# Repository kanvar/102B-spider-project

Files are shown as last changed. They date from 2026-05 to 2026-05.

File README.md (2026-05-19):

# Spider Seeder Summary

The Spider Seeder Robot was built for ME 102B, Spring 2026 — it's a six-legged robot that plants seeds in rough terrain. The idea is for ecological restoration work, where you need to get a lot of seeds into uneven ground and doing it by hand is slow while big machinery isn't precise enough and cannot navigate the rough terrain. There are five subsystems: the six-legged chassis, a 12V DC motor drill, a stepper-driven seed dispenser, the sensors, and an ESP32 handling control and communications.

The robot can walk, but we decided to have it plant from a fixed standing position instead of dealing with full gait planning. It runs an event-driven state machine: lower the body using the servos to push the drill into the soil, retract, drop the seeds, move over, then sweep a leg over to cover the hole. Skipping the walking let us put our effort into making the planting sequence flawless, which made sense for our assignment.

On the electrical side, the ESP32 runs the state machine (IDLE → DRILLING → SEEDING → COVERING, with a global ABORT), handles WiFi, and drives all the I/O. Two PCA9685 boards run the 18 servos over I²C, a VNH5019 driver handles the 12 V drill motor, and a ULN2003 board runs the seed stepper. The part I'm most proud of ont his bot is the custom power distribution board I soldered in order to take power from the battery and distribute it to all components. There's also an IR flame sensor that triggers an immediate abort if it goes off. Due to our extreme electronics setup for a Mechanical Engineering course (extremly overkill) we were honored with reciving the award for the best Electromechanical Design award.

This GitHub has the final mechanical, electrical, and software development for the project as well as our final report. The biggest thing for future improvements: define the state machine, and define electronics before trying to mechanically integrate. We learned this the hard way — we selected most of our electronics after the main design and caused lots of sizing and late prototypying which was the reason we couldn't fully demo our walking sequence.

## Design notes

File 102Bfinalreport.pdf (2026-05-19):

ME 102B · Mechatronics Design · Spring 2026 | Spider Seeder Robot

Spider Seeder
ME 102B — Mechatronics Design · Spring 2026 | Team #21
Kanvar Soin | Raul Hernandez | Mark Polezhaev | Jesse Ramirez | Carlos Avina
| | May 14, 2026

### 1. Opportunity

Ecological restoration requires planting large numbers of seeds in uneven, remote terrain where manual methods are labor intensive and conventional machinery lacks precision. The Spider Seeder Robot fills this gap with a compact, autonomous platform that navigates rough ground, drills to consistent depth, and dispenses seeds in a single integrated cycle using low-cost components suited for replication and future development.

### 2. System Overview and High-Level Strategy

The robot integrates five subsystems: a six-legged servo-driven chassis, a DC motor drill, a stepper-motor seed dispenser, a sensor suite, and an ESP32 control and communication layer (Figure 1).
The robot has the ability to achieve locomotion; however, the robot plants from a fixed standing position using an event-driven state machine: it lowers its body via coxa servo deflection to drive the drill into soil, retracts, dispenses seeds, and sweeps a leg to cover the hole. This focused the control effort on depth sensing and actuation reliability over gait planning, appropriate for a first-generation prototype.

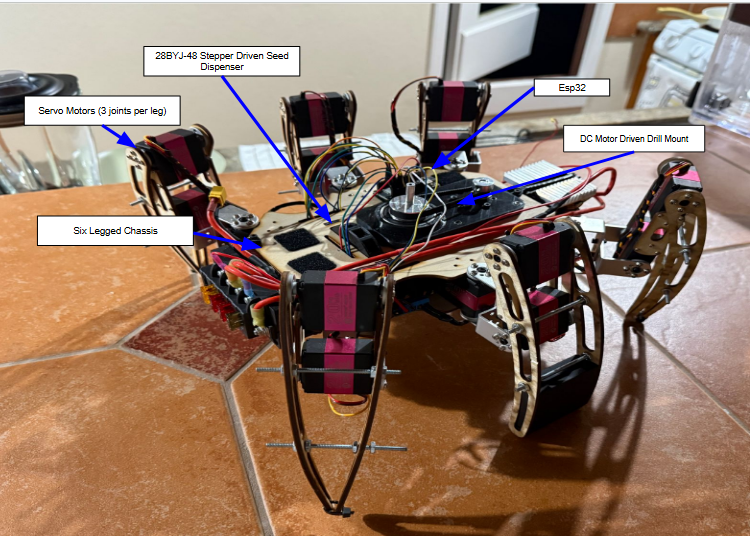
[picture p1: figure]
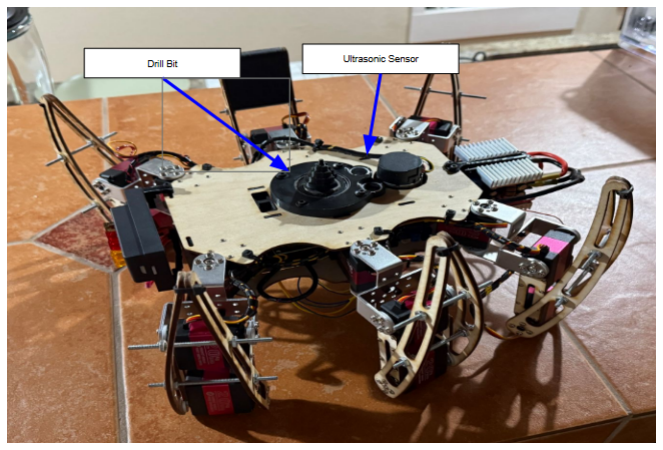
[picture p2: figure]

(a) Annotated top view. | (b) Annotated bottom view.
Figure 1: Annotated photos of the fully assembled Spider Seeder Robot. The labeled views identify the main mechanical, sensing, and actuation subsystems, including the six-legged chassis, servo motors, drill subsystem, ultrasonic sensor, ESP32 controller, and stepper-driven seed dispenser. These photos serve as a visual reference for the integrated prototype and the key components used during the planting sequence.

### 3. Desired vs. Achieved Specifications

Table 1 compares design targets against achieved performance. Values marked XX will be filled with measured results from final testing.

Table 1: Design targets vs. achieved specifications.

Parameter | Target | Achieved
Drilling depth | 5 cm | 7 cm
Drill motor actuation | Full PWM (12 V, 255/255) | Full PWM (12 V, 255/255)
Body descent range (coxa) 90→45 | 90→45
Depth sensing method | Tare + relative threshold | Implemented, ±0.5 cm
Covering sweep reps | 2 reps | 2 reps

### 4. Electrical and Control Architecture

The ESP32 manages the state machine, WiFi communication, and all I/O. Two PCA9685 PWM boards drive the 18 MG996R servos over I²C, while freeing ESP32 PWM channels. The 12 V drill motor is controlled through a VNH5019 driver, and the 28BYJ-48 seed stepper is driven by a ULN2003 board. All pin assignments are stored in Config.h.
Sensors: The HC-SR04 supports closed-loop depth control using tareDistance(), which averages five IDLE baseline readings and compares later drilling readings within ±0.5 cm. The normally-high IR flame sensor is checked every loop and immediately triggers ABORT if activated.
Communication: The ESP32 hosts the SpiderRobot 102B WiFi access point. The browser GUI sends commands through GET /command?cmd=... and polls GET /status every 1.5 s for JSON telemetry.
Figure 2 shows the full circuit diagram.

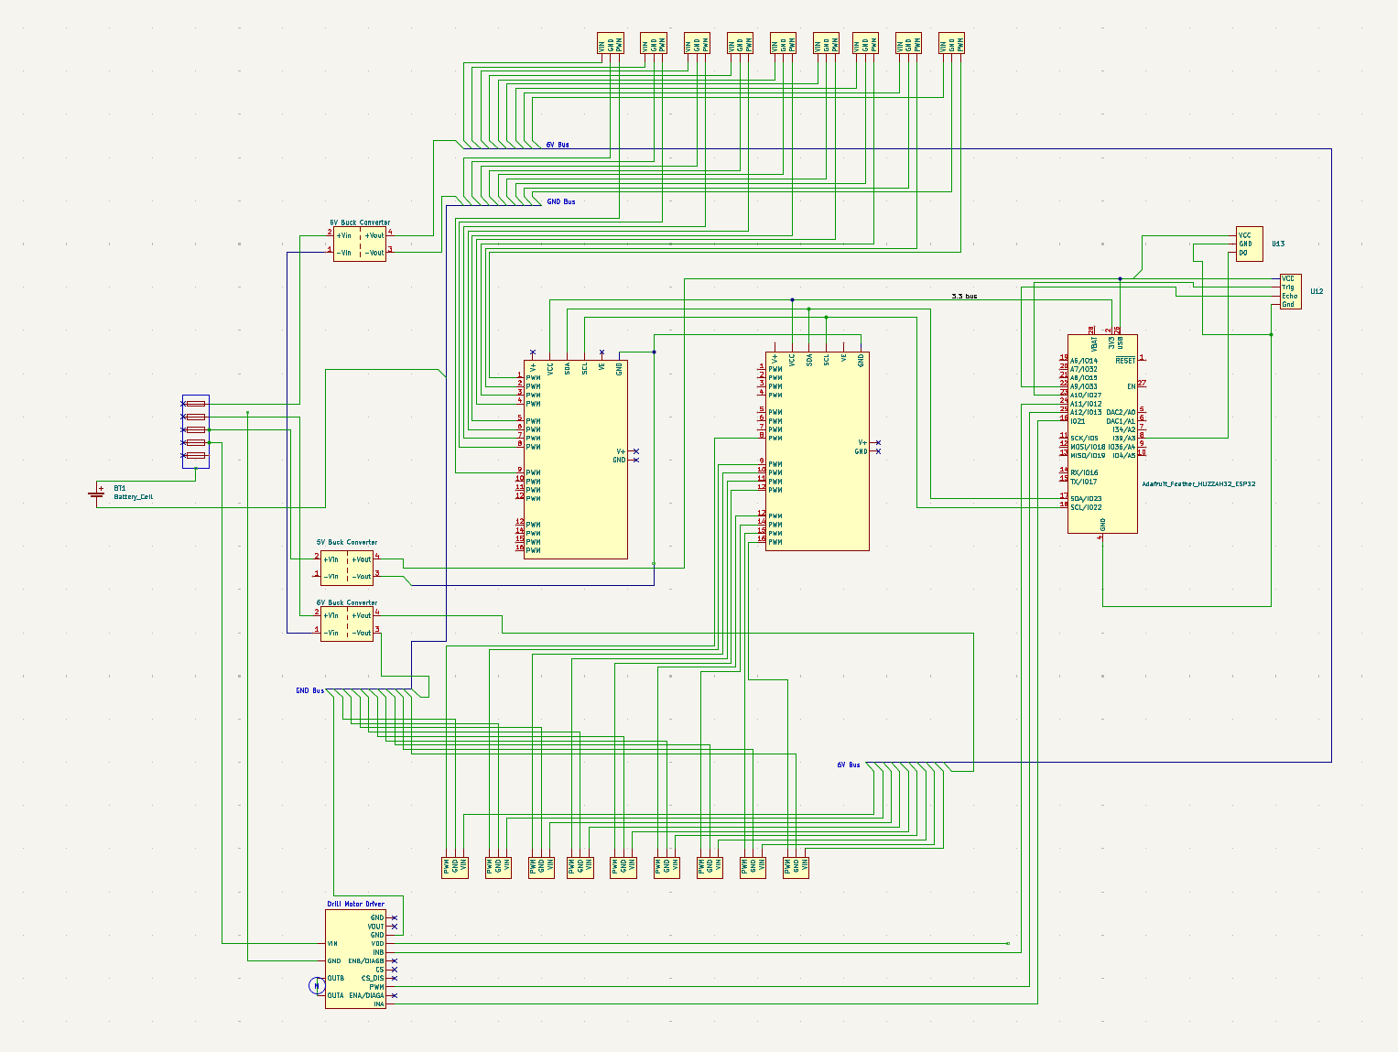
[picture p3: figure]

Figure 2: Circuit diagram showing ESP32 GPIO assignments, PCA9685 I²C servo driver connections, L298N drill motor driver, ULN2003 stepper driver, HC-SR04 ultrasonic wiring, IR flame sensor input, and power distribution.

### 5. State Machine and Event-Driven Logic

The robot’s behavior is governed by a finite state machine implemented in StateMachine.cpp. Each state has a dedicated service function with a static bool firstEntry guard that executes one-time initialization on state entry and ongoing per-loop logic on subsequent calls. stateMachineLoop() is called every Arduino loop() iteration, ensuring non-blocking operation except during the SEEDING and COVERING phases, which use blocking delay() calls for actuator timing precision.
Table 2 describes each state, its entry action, and its exit condition. Figure 3 shows the transition diagram.

Table 2: State machine summary.

State | Entry action | Exit condition
IDLE | Zero all 18 servos; tare ul- trasonic baseline (5-sample
| avg) | Operator | sends
| | STATE:DRILLING | via
| | GUI
DRILLING | Drill ON; lower body (coxa
| 90 → 45), then lift; speed
| scales with distance

Returns to baseline ±0.5 cm
| | or coxa reaches 90
SEEDING | Drill OFF; stepper rotates
| 2500 steps

Stepper completes (auto-
| | advance)
COVERING Right-middle leg sweeps
| C/F; 2× reps

Animation completes (auto-
| | advance to IDLE)
ABORT | All actuators disabled | Operator | sends

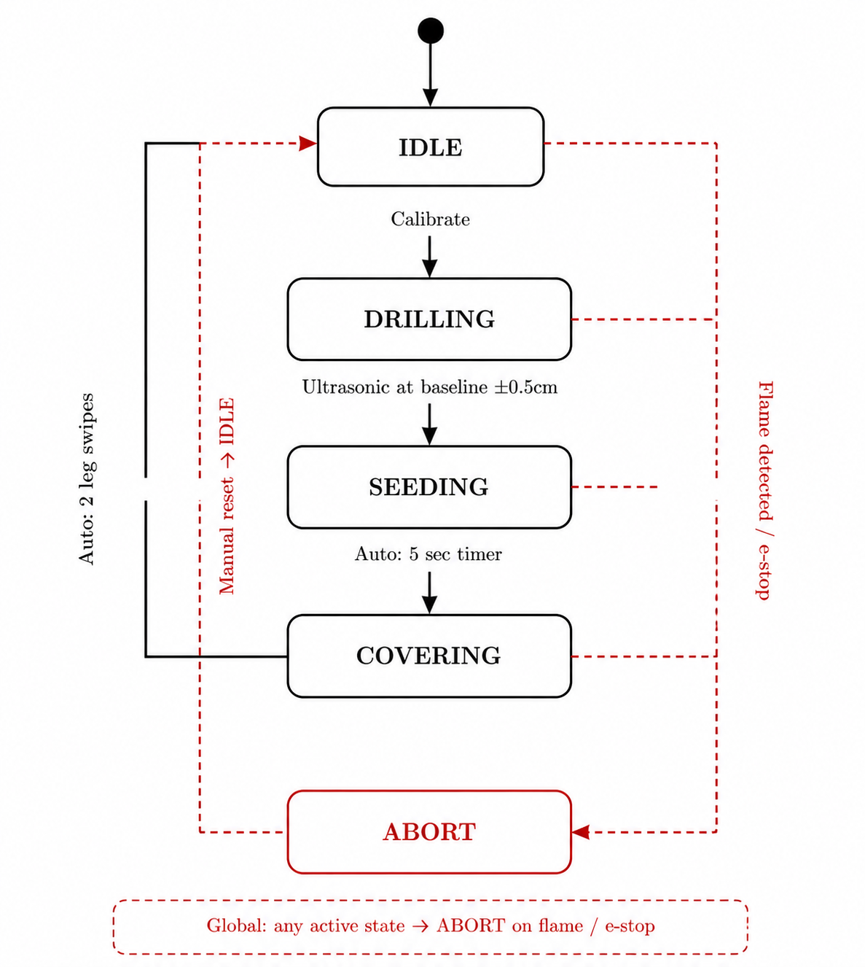
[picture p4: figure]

STATE:IDLE | Figure 3: State transition diagram.

### 6. Function-Critical Decisions and Calculations

### 6.1. Coxa Servo Selection — Body-Lowering Torque

Each of the six coxa servos must support 1
6

of the robot’s weight through a moment arm equal to femur length L = 7 in = 0.178 m:

τreq =

m g
6
- L =

3.205 × 9.81
6
× 0.178 ≈ 0.932 N m | (1)

The installed servo is rated at 20 kg cm = 1.962 N m, yielding a design safety factor of SF = 1.962 / 0.932 ≈ 2.1, providing margin for dynamic loads during soil penetration.

### 6.2. Drill Motor Driver Selection

The Pololu 25D gearmotor operates at 12 V with a rated operating current of Iop = 0.82 A (at peak efficiency):

Pin = V · Iop = 12 × 0.82 = 9.84W | (2)

delivering a maximum mechanical output of 8.9W at 44 % efficiency. Stall current is Istall = 5.0 A. The VNH5019 motor driver is rated at 12 A continuous (30 A peak), providing a driver safety factor of 12 / 5.0 = 2.4 even at stall, well within the thermal envelope for the 60 s maximum drill cycle.

### 6.3. Ultrasonic Depth Sensing — Tare-and-Compare Algorithm

Rather than a fixed threshold, tareDistance() samples five readings at IDLE entry to establish a terrain-relative baseline. The DRILLING-to-SEEDING transition fires when:

|dmeasured − dbaseline| ≤ 0.5 cm | (3)

This makes depth control invariant to terrain height, mounting variation, and battery sag, at the cost of a brief initialization delay per cycle.

### 7. Reflection for Future Students

The most useful decision was defining the state machine, WiFi command protocol, and /status JSON format before full firmware integration. This gave the team a shared interface and made debugging easier.
Future teams should lock all pin assignments in Config.h during initial wiring and build telemetry into the system from the beginning. Adding the telemetry endpoint late required changes across multiple files and introduced a connection-loss bug.

A. Bill of Materials
Component | Description / Supplier | Qty | Unit $ | Total $

Actuation
Servo Motor | 20 kg·cm, AliExpress | 18 | 10.74 | 252.13
Gearmotor (Drill) | 12 V brushed DC, Pololu | 1 | 56.00 | 69.90
Stepper Motor | NEMA seed dispenser, Stepper Online | 1 | 20.49 | 20.49

Electronics / Control
PWM Expander | PCA9685 16-ch I²C, Amazon | 2 | 9.99 | 21.28
Motor Driver | Pololu VNH5019, drill motor | 1 | 12.95 | 14.21
Logic Converter | Bi-directional 3.3 V/5 V, Amazon | 1 | 4.99 | 6.29
IR Flame Sensor | Digital, 760–1100 nm, Amazon | 1 | 7.99 | 9.29
HC-SR04 Ultrasonic | 2–400 cm, on hand | 1 | – | 0.00
Capacitors | Servo rail bulk caps, Amazon | 1 | 6.99 | 8.29
Protoboard | Amazon | 2 | 8.99 | 19.28

Power
3S LiPo Battery | 5200 mAh, XT60, Amazon | 2 | – | 90.34
5A Buck Converter | 5 V output, Amazon | 1 | 14.99 | 16.29
12V Buck Converter | 12 V output, Amazon | 1 | 12.99 | 14.29
Power Dist. Board | Amazon | 1 | 6.99 | 8.29
Terminal Block | Amazon | 1 | 14.99 | 14.99
Grounding Bus | 6-position brass terminal, Amazon | 1 | 8.39 | 9.69
XT60 Connector | Amazon | 1 | 9.89 | 11.19
30 A Fuse | Amazon | 1 | 4.86 | 6.16

Mechanical Structure
Aluminum 6061 | Assorted cuts, Jacobs/Amazon | – | – | 114.24
Timing Pulley 2GT | 2-piece set, Amazon | 1 | 8.99 | 9.91
Bearing | Amazon | 1 | 16.99 | 22.03
Drill Brackets | Pololu | 1 | 10.95 | 12.22
Step Drill Bit | Home Depot | 1 | 8.97 | 10.17
Coupler (Drill) | Walmart | 1 | 9.99 | 10.76
Aluminum Shaft | Amazon | 1 | 9.99 | 11.29
Hardware | M3/M4 screws, McMaster/on hand | – | – | 3.11
Sleeve Tube | Amazon | 1 | 7.99 | 9.29

Wiring / Connectors
Wire, assorted | 14–24 AWG, Amazon | – | – | 123.46
Wire Tubing | Amazon | 1 | 10.00 | 11.30
Heat Shrink Kit | Amazon | 1 | 9.99 | 11.29
Banana Connectors | Male/female set, Amazon | 1 | 9.99 | 11.29
Pin Headers | Amazon | 1 | 11.99 | 13.29

Miscellaneous
Seeds | Amazon | 1 | 5.41 | 5.41
Adhesive Pads | Amazon | 1 | 8.99 | 8.99
Connector Kit | 80 pc assorted, Amazon | 1 | 4.99 | 4.99
Breadboard | On hand | 1 | – | 0.00
| | | Total | $993.73
B. CAD Images

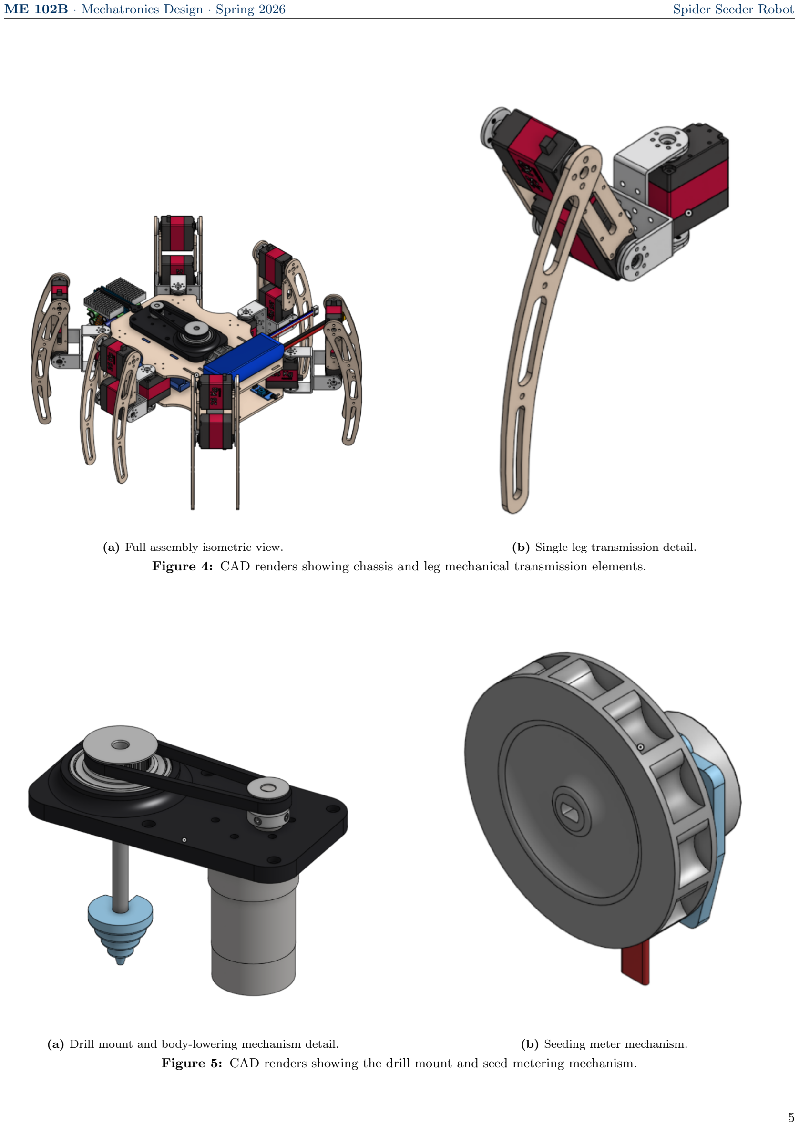
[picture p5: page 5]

(a) Full assembly isometric view. | (b) Single leg transmission detail.
Figure 4: CAD renders showing chassis and leg mechanical transmission elements.
(a) Drill mount and body-lowering mechanism detail. | (b) Seeding meter mechanism.
Figure 5: CAD renders showing the drill mount and seed metering mechanism.

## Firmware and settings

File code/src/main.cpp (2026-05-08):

#include <Arduino.h>
#include "control/StateMachine.h"
#include "control/WiFiCommand.h"
#include "actuators/DrillMotor.h"
#include "actuators/SeederMotor.h"
#include "motion/LegController.h"
#include "sensors/DistanceSensor.h"

DrillMotor drill;
SeederMotor seeder;

void setup() {
  Serial.begin(115200);
  delay(200);

  drill.begin();
  seeder.begin();
  legSetup();
  distanceSensorSetup();
  wifiCommandSetup();
  stateMachineSetup();
}

void loop() {
  wifiCommandLoop();
  stateMachineLoop();
}

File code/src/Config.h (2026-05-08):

#pragma once
#ifndef CONFIG_H
#define CONFIG_H
#include <stdint.h>


struct ServoAddr { uint8_t bus; uint8_t ch; };


constexpr ServoAddr leftFront_H = { 0x40, 2 };
constexpr ServoAddr leftFront_C = { 0x40, 3 };
constexpr ServoAddr leftFront_F = { 0x40, 0 };

constexpr ServoAddr leftMiddle_H = { 0x60, 7 };
constexpr ServoAddr leftMiddle_C = { 0x60, 5 };
constexpr ServoAddr leftMiddle_F = { 0x60, 6 };

constexpr ServoAddr leftBack_H = { 0x40, 7 };
constexpr ServoAddr leftBack_C = { 0x40, 5 };
constexpr ServoAddr leftBack_F = { 0x40, 6 };


constexpr ServoAddr rightFront_H = { 0x60, 13 };
constexpr ServoAddr rightFront_C = { 0x60, 14 };
constexpr ServoAddr rightFront_F = { 0x60, 15 };

constexpr ServoAddr rightMiddle_H = { 0x60, 10 };
constexpr ServoAddr rightMiddle_C = { 0x60, 11 };
constexpr ServoAddr rightMiddle_F = { 0x60, 9 };

constexpr ServoAddr rightBack_H = { 0x40, 12 };
constexpr ServoAddr rightBack_C = { 0x40, 14 };
constexpr ServoAddr rightBack_F = { 0x40, 13 };

constexpr int TRIG_PIN = 4;
constexpr int ECHO_PIN = 5;

constexpr int FIRE_SENSOR_PIN = 15;

constexpr int DRILL_INA_PIN = 13;
constexpr int DRILL_INB_PIN = 33;
constexpr int DRILL_PWM_PIN = 27;


constexpr int SEEDER_IN1_PIN = 19;
constexpr int SEEDER_IN2_PIN = 21;
constexpr int SEEDER_IN3_PIN = 14;
constexpr int SEEDER_IN4_PIN = 32;


constexpr float PLANT_THRESHOLD_CM = 10.0;
constexpr float WALK_THRESHOLD_CM  = 10.0;


constexpr int DRILL_DEFAULT_SPEED = 255;


constexpr int SEEDER_STEPS_PER_REV = 400;
constexpr int SEEDER_STEP_DELAY_MS = 2;


constexpr unsigned long SENSOR_INTERVAL_MS = 100;
constexpr unsigned long GAIT_STEP_MS       = 600;
constexpr unsigned long IDLE_PRINT_MS      = 1000;

constexpr const char* WIFI_AP_SSID = "SpiderRobot_102B";
constexpr const char* WIFI_AP_PASSWORD = "123456789";

#endif

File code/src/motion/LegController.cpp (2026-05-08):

#include <Arduino.h>
#include <Wire.h>
#include <Adafruit_PWMServoDriver.h>
#include "LegController.h"
#include "../Config.h"

static Adafruit_PWMServoDriver pwmBack = Adafruit_PWMServoDriver(0x40);
static Adafruit_PWMServoDriver pwmFront = Adafruit_PWMServoDriver(0x60);

// PWM frequency for hobby servos
#define SERVO_FREQ_HZ 50

#define PULSE_MIN_TICKS 102
#define PULSE_MAX_TICKS 512


void legSetup()
{
  Serial.println("LegController: setup");

  Wire.begin(22, 20); // SDA, SCL

  pwmBack.begin();
  pwmBack.setPWMFreq(SERVO_FREQ_HZ);

  pwmFront.begin();
  pwmFront.setPWMFreq(SERVO_FREQ_HZ);

  delay(100);

  Serial.println("LegController: both boards initialized");
}


void writeServoAngle(uint8_t bus, uint8_t channel, int angle)
{
  if (angle < 0)
    angle = 0;
  if (angle > 180)
    angle = 180;

  int ticks = map(angle, 0, 180, PULSE_MIN_TICKS, PULSE_MAX_TICKS);

  // Send to the correct board
  if (bus == 0x40)
  {
    pwmBack.setPWM(channel, 0, ticks);
  }
  else if (bus == 0x60)
  {
    pwmFront.setPWM(channel, 0, ticks);
  }
  else
  {
    Serial.print("LegController: unknown bus 0x");
    Serial.println(bus, HEX);
  }
}

void zeroAllServos()
{
  Serial.println("LegController: setting all servos to starting pose");

  writeServoAngle(leftFront_H.bus, leftFront_H.ch, 90);
  writeServoAngle(leftMiddle_H.bus, leftMiddle_H.ch, 90);
  writeServoAngle(leftBack_H.bus, leftBack_H.ch, 90);
  writeServoAngle(rightFront_H.bus, rightFront_H.ch, 90);
  writeServoAngle(rightMiddle_H.bus, rightMiddle_H.ch, 90);
  writeServoAngle(rightBack_H.bus, rightBack_H.ch, 90);
  delay(100);


  writeServoAngle(leftFront_C.bus, leftFront_C.ch, 90);
  writeServoAngle(leftMiddle_C.bus, leftMiddle_C.ch, 90);
  writeServoAngle(leftBack_C.bus, leftBack_C.ch, 90);
  writeServoAngle(rightFront_C.bus, rightFront_C.ch, 90);
  writeServoAngle(rightMiddle_C.bus, rightMiddle_C.ch, 90);
  writeServoAngle(rightBack_C.bus, rightBack_C.ch, 90);
  delay(100);


  writeServoAngle(leftFront_F.bus, leftFront_F.ch, 10);
  writeServoAngle(leftMiddle_F.bus, leftMiddle_F.ch, 10);
  writeServoAngle(leftBack_F.bus, leftBack_F.ch, 10);
  writeServoAngle(rightFront_F.bus, rightFront_F.ch, 10);
  writeServoAngle(rightMiddle_F.bus, rightMiddle_F.ch, 10);
  writeServoAngle(rightBack_F.bus, rightBack_F.ch, 10);
  delay(100);

  Serial.println("LegController: starting pose set");
}

void walkingIDLE()
{
  Serial.println("LegController: setting all servos to walking pose");

  writeServoAngle(leftFront_H.bus, leftFront_H.ch, 90);
  writeServoAngle(leftMiddle_H.bus, leftMiddle_H.ch, 90);
  writeServoAngle(leftBack_H.bus, leftBack_H.ch, 90);
  writeServoAngle(rightFront_H.bus, rightFront_H.ch, 90);
  writeServoAngle(rightMiddle_H.bus, rightMiddle_H.ch, 90);
  writeServoAngle(rightBack_H.bus, rightBack_H.ch, 90);
  delay(100);

  writeServoAngle(leftFront_C.bus, leftFront_C.ch, 110);
  writeServoAngle(leftMiddle_C.bus, leftMiddle_C.ch, 110);
  writeServoAngle(leftBack_C.bus, leftBack_C.ch, 110);
  writeServoAngle(rightFront_C.bus, rightFront_C.ch, 110);
  writeServoAngle(rightMiddle_C.bus, rightMiddle_C.ch, 110);
  writeServoAngle(rightBack_C.bus, rightBack_C.ch, 110);
  delay(100);

  writeServoAngle(leftFront_F.bus, leftFront_F.ch, 40);
  writeServoAngle(leftMiddle_F.bus, leftMiddle_F.ch, 40);
  writeServoAngle(leftBack_F.bus, leftBack_F.ch, 40);
  writeServoAngle(rightFront_F.bus, rightFront_F.ch, 40);
  writeServoAngle(rightMiddle_F.bus, rightMiddle_F.ch, 40);
  writeServoAngle(rightBack_F.bus, rightBack_F.ch, 40);
  delay(100);

  Serial.println("LegController: starting pose set");
}

void seedingMoveForward()
{
  const int leftStart = 90;
  const int rightStart = 90;
  const int leftTarget = 120;
  const int rightTarget = 60;
  const int stepDelayMs = 10;

  int leftStep = (leftStart < leftTarget) ? 1 : -1;
  int rightStep = (rightStart < rightTarget) ? 1 : -1;

  int leftAngle = leftStart;
  int rightAngle = rightStart;

  while (leftAngle != leftTarget || rightAngle != rightTarget)
  {
    if (leftAngle != leftTarget)
      leftAngle += leftStep;
    if (rightAngle != rightTarget)
      rightAngle += rightStep;

    writeServoAngle(leftFront_H.bus, leftFront_H.ch, leftAngle);
    writeServoAngle(leftMiddle_H.bus, leftMiddle_H.ch, leftAngle);
    writeServoAngle(leftBack_H.bus, leftBack_H.ch, leftAngle);
    writeServoAngle(rightFront_H.bus, rightFront_H.ch, rightAngle);
    writeServoAngle(rightMiddle_H.bus, rightMiddle_H.ch, rightAngle);
    writeServoAngle(rightBack_H.bus, rightBack_H.ch, rightAngle);

    delay(stepDelayMs);
  }
}

void sideStepRight()
{
  writeServoAngle(leftFront_C.bus, leftFront_C.ch, 75);
  writeServoAngle(leftBack_C.bus, leftBack_C.ch, 75);
  writeServoAngle(leftFront_F.bus, leftFront_F.ch, 30);
  writeServoAngle(leftBack_F.bus, leftBack_F.ch, 30);
  writeServoAngle(leftFront_H.bus, leftFront_H.ch, 60);
  writeServoAngle(leftBack_H.bus, leftBack_H.ch, 120);
  delay(1000);
  writeServoAngle(leftFront_F.bus, leftFront_F.ch, 70);
  writeServoAngle(leftBack_F.bus, leftBack_F.ch, 70);
  writeServoAngle(leftFront_C.bus, leftFront_C.ch, 150);
  writeServoAngle(leftBack_C.bus, leftBack_C.ch, 150);
  delay(1000);
  writeServoAngle(rightMiddle_C.bus, rightMiddle_C.ch, 100);
  writeServoAngle(leftMiddle_C.bus, leftMiddle_C.ch, 70);
  writeServoAngle(leftMiddle_F.bus, leftMiddle_F.ch, 30);
  writeServoAngle(rightFront_C.bus, rightFront_C.ch, 70);
  writeServoAngle(rightBack_C.bus, rightBack_C.ch, 70);
  writeServoAngle(rightFront_F.bus, rightFront_F.ch, 30);
  writeServoAngle(rightBack_F.bus, rightBack_F.ch, 30);
  delay(1000);

  const int stepDelayMs = 20;

  int lfF = 70;
  int lfC = 150;
  int rmC = 90;
  int rmF = 10;

  const int lfF_end = 10;
  const int lfC_end = 90;
  const int rmC_end = 150;
  const int rmF_end = 70;

  while (lfF != lfF_end || lfC != lfC_end || rmC != rmC_end || rmF != rmF_end)
  {
    if (lfF != lfF_end)
      lfF--; // 70  -> 10
    if (lfC != lfC_end)
      lfC--; // 150 -> 90
    if (rmC != rmC_end)
      rmC++; // 90  -> 150
    if (rmF != rmF_end)
      rmF++; // 10  -> 70

    writeServoAngle(leftFront_F.bus, leftFront_F.ch, lfF);
    writeServoAngle(leftBack_F.bus, leftBack_F.ch, lfF);
    writeServoAngle(leftFront_C.bus, leftFront_C.ch, lfC);
    writeServoAngle(leftBack_C.bus, leftBack_C.ch, lfC);
    writeServoAngle(rightMiddle_C.bus, rightMiddle_C.ch, rmC);
    writeServoAngle(rightMiddle_F.bus, rightMiddle_F.ch, rmF);

    delay(stepDelayMs);
  }

  delay(1000);

  writeServoAngle(leftMiddle_C.bus, leftMiddle_C.ch, 100);
  writeServoAngle(leftMiddle_F.bus, leftMiddle_F.ch, 10);
  writeServoAngle(rightFront_C.bus, rightFront_C.ch, 100);
  writeServoAngle(rightBack_C.bus, rightBack_C.ch, 100);
  delay(1000);
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

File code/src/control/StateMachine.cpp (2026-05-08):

#include <Arduino.h>
#include "StateMachine.h"
#include "SerialCommand.h"
#include "WiFiCommand.h"
#include "../motion/LegController.h"
#include "../sensors/DistanceSensor.h"
#include "../actuators/DrillMotor.h"
#include "../actuators/SeederMotor.h"
#include "../Config.h"

extern SeederMotor seeder;
extern DrillMotor drill;

State currentState = IDLE;

//drill configuration

#define DRILL_TRIGGER_CM 3.0
#define COXA_START_ANGLE 90
#define COXA_MIN_ANGLE 45

#define DESCENT_FAR_DISTANCE 20.0
#define DESCENT_NEAR_DISTANCE 5.0
#define DESCENT_FAST_MS 30
#define DESCENT_SLOW_MS 200

#define DRILLING_PHASE_DESCEND 0
#define DRILLING_PHASE_LIFT 1

#define BASELINE_TOLERANCE_CM 0.5

//helper function: state to string

const char *stateToString(State s)
{
  switch (s)
  {
  case IDLE:
    return "IDLE";
  case DRILLING:
    return "DRILLING";
  case SEEDING:
    return "SEEDING";
  case COVERING:
    return "COVERING";
  case ABORT:
    return "ABORT";
  default:
    return "UNKNOWN";
  }
}

//helper function: delay for drilling

unsigned long computeStepDelay(float distance)
{
  if (distance < 0)
  {
    return DESCENT_SLOW_MS;
  }
  else if (distance >= DESCENT_FAR_DISTANCE)
  {
    return DESCENT_FAST_MS;
  }
  else if (distance <= DESCENT_NEAR_DISTANCE)
  {
    return DESCENT_SLOW_MS;
  }
  else
  {
    float t = (distance - DESCENT_NEAR_DISTANCE) /
              (DESCENT_FAR_DISTANCE - DESCENT_NEAR_DISTANCE);
    return DESCENT_SLOW_MS +
           (unsigned long)((DESCENT_FAST_MS - DESCENT_SLOW_MS) * t);
  }
}

//helper function: slow the servos down

void smoothMoveServoAngle(uint8_t bus, uint8_t ch, int startAngle, int endAngle, int stepDelayMs)
{
  if (startAngle < endAngle)
  {
    for (int angle = startAngle; angle <= endAngle; angle++)
    {
      writeServoAngle(bus, ch, angle);
      delay(stepDelayMs);
    }
  }
  else
  {
    for (int angle = startAngle; angle >= endAngle; angle--)
    {
      writeServoAngle(bus, ch, angle);
      delay(stepDelayMs);
    }
  }
}


void stateMachineSetup()
{
  Serial.println("StateMachine: setup");

  currentState = IDLE;

  Serial.print("StateMachine: starting in ");
  Serial.println(stateToString(currentState));
}

//IDLE state

void serviceIdle()
{
  static bool firstEntry = true;

  if (firstEntry)
  {
    Serial.println("IDLE: first entry — zeroing servos and taring ultrasonic");
    // walkingIDLE();
    zeroAllServos();
    delay(2000);
    tareDistance();

    firstEntry = false;

    Serial.println("IDLE: setup complete, monitoring for trigger");
  }

  readDistanceIfReady();

  if (currentState != IDLE)
  {
    firstEntry = true;
  }
}

//drilling state

void serviceDrilling()
{
  static bool firstEntry = true;
  static int currentCoxaAngle = COXA_START_ANGLE;
  static unsigned long lastStepTime = 0;
  static int phase = DRILLING_PHASE_DESCEND;

  if (firstEntry)
  {
    zeroAllServos();
    Serial.println("DRILLING: first entry — drill on, beginning descent");

    drill.on();

    currentCoxaAngle = COXA_START_ANGLE;
    setAllCoxas(currentCoxaAngle);

    phase = DRILLING_PHASE_DESCEND;
    lastStepTime = millis();
    firstEntry = false;
  }

  float distance = readDistanceIfReady();

  // lowering phase
  if (phase == DRILLING_PHASE_DESCEND)
  {

    bool atGround = (distance > 0 && distance <= DRILL_TRIGGER_CM);
    bool atMinAngle = (currentCoxaAngle <= COXA_MIN_ANGLE);

    if (atGround || atMinAngle)
    {
      Serial.println("DRILLING: descent complete, beginning lift");
      phase = DRILLING_PHASE_LIFT;
      lastStepTime = millis();
    }
    else
    {
      unsigned long stepDelay = computeStepDelay(distance);

      if (millis() - lastStepTime >= stepDelay)
      {
        lastStepTime = millis();
        currentCoxaAngle--;
        setAllCoxas(currentCoxaAngle);

        Serial.print("DRILLING [DESCEND]: coxa=");
        Serial.print(currentCoxaAngle);
        Serial.print(" distance=");
        Serial.print(distance);
        Serial.print(" step_delay=");
        Serial.println(stepDelay);
      }
    }
  }

  // lift phase
  else if (phase == DRILLING_PHASE_LIFT)
  {

    // Hard stop: never lift past 90°
    if (currentCoxaAngle >= COXA_START_ANGLE)
    {
      Serial.println("DRILLING: lift complete (reached 90°) — drill off, advancing to SEEDING");
      drill.off();
      firstEntry = true;
      currentState = SEEDING;
      Serial.println("STATE_ACK:SEEDING");
      return;
    }

    float relative = readRelativeDistanceIfReady();
    if (relative > -9000.0 && abs(relative) <= BASELINE_TOLERANCE_CM)
    {
      Serial.print("DRILLING: returned to baseline (rel=");
      Serial.print(relative);
      Serial.println(") — drill off, advancing to SEEDING");
      drill.off();
      delay(1000);
      firstEntry = true;
      currentState = SEEDING;
      Serial.println("STATE_ACK:SEEDING");
      return;
    }

    unsigned long stepDelay = computeStepDelay(distance);

    if (millis() - lastStepTime >= stepDelay)
    {
      lastStepTime = millis();
      currentCoxaAngle++;
      setAllCoxas(currentCoxaAngle);

      Serial.print("DRILLING [LIFT]: coxa=");
      Serial.print(currentCoxaAngle);
      Serial.print(" distance=");
      Serial.print(distance);
      Serial.print(" step_delay=");
      Serial.println(stepDelay);
    }
  }

  if (currentState != DRILLING)
  {
    firstEntry = true;
  }
}

// seeding state

void serviceSeeding()
{
  static bool firstEntry = true;

  if (firstEntry)
  {
    seedingMoveForward();
    delay(2000);

    Serial.println("SEEDING: running seeder");

    seeder.rotateSteps(700);

    Serial.println("SEEDING: advancing to COVERING");
    zeroAllServos();

    firstEntry = false;
    currentState = COVERING;
    Serial.println("STATE_ACK:COVERING");
  }

  if (currentState != SEEDING)
  {
    firstEntry = true;
  }
}

//covering state
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

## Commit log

2026-04-21 Initialcode base with GUI, working state machine, and working leg + US sensor.
2026-04-29 wifi connection + GUI resolve
    [LegController.cpp, SerialCommand.cpp, StateMachine.cpp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]
2026-05-11 CAD and Electronics added
    [spider final.kicad_pcb, spider final.kicad_sch]
